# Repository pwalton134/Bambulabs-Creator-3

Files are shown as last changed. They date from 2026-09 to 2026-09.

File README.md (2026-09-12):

# Bambulabs-Creator-3
A repo containing all the mods I have made to my Flashforge Creator 3 (not pro) to bring it back to life.
THIS REPO IS AN ON-GOING WORK IN PROGRESS!
Treat it as my notepad, where I am writing what I have done to get an ageing FFC3 going again.

<h1>Alternative Slicers</h1>
Flashforge proprietary tools work well, but are dated. I wanted some of the newer more advanced slicer tools that allowed me to tinker with the settings. I found profiles for Ultimaker Cura and Orcaslicer. Neither connect directly over Ethernet, but I only use the USB drive anyway so I haven't chased this far.

<H2>Orcaslicer</H2>
This has been the most successful thus far, I found profiles that worked well from the Orcaslicer Github page, https://github.com/OrcaSlicer/OrcaSlicer/issues/9577.

<H2>Ultimaker Cura</H2>
This worked well, but I moved to Orcaslicer when that worked as I found the interface a lot better, and less buggy in Fedora. *reminder to dig out link and add here*.

<h1>Replacement Hotends</h1>
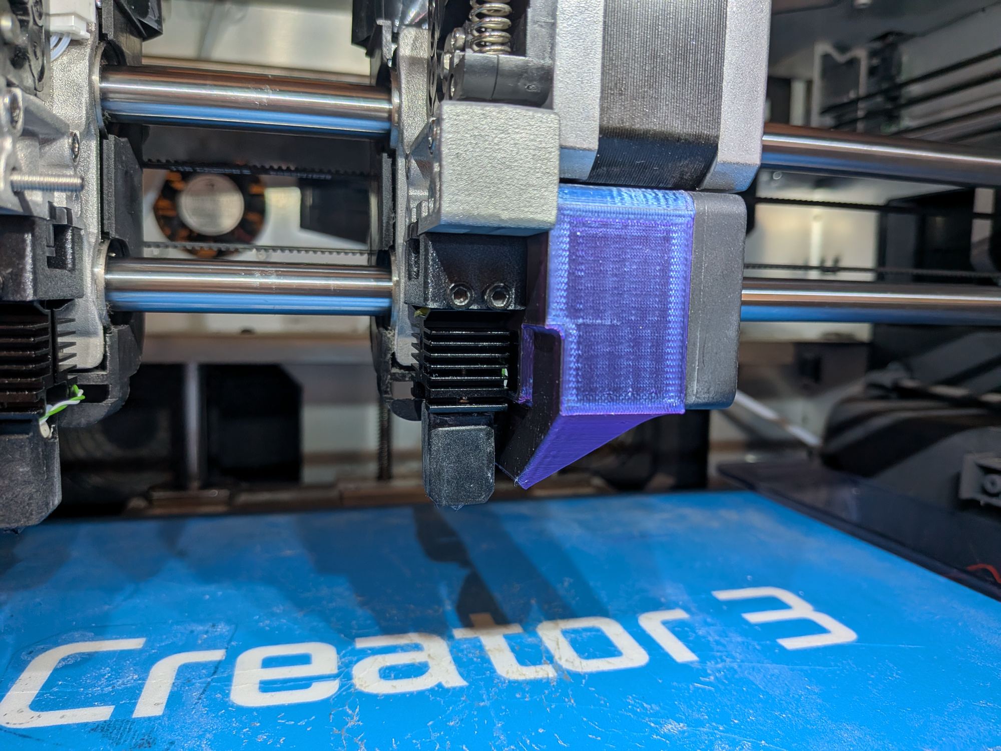
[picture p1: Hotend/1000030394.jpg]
X1C hotend installed


*These notes are being added to as I find time. I intend to add pictures and more of my learnings along the way*
My printer was a freebie from my work as they could not get replacement hotends, ultimately giving up and going to Bambu Labs printers. Obviously, getting the hotends working again was a major hurdle to overcome, as the prints were pretty awful when it did work, and the nozzles forever clogging.

To resolve this, I decided to look at what printers were out there, and what I could get on Amazon cheaply. I found the X1C hotend to be a particularly good match. It was 24V, and a similar resistance to the FFC3 hotend, and similar length. For $24 AUD I gave it a go and it was surprisingly straightforward to install. All it took was a simple 3D printed adapter, K-type thermocouple, and, using existing hardware it was surprisingly straightforward.

Things I learned along the way:
- Printer is 24V, including the hotend
- Bed homing sensor is piezo
- Temperature sensor is a K-type thermocouple
- Manual calibration of nozzle height negates the need for the homing sensor

<h2>Method:</h2>
<h3>Parts Required:</h3>

- Bambu Labs X1C 0.4mm hotend (I used this clone from Amazon https://www.amazon.com.au/LEOWAY-Upgraded-Printer-Hotend-Assembly/dp/B0GZF311Z4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)
- K-type thermocouple (bare wire worked for me)
- JST-XH 2.5mm 2P receptacle (optional, for heater wire)
- 22AWG silicone wire (optional, for heater wire)
	- Qty:2 ~90mm lengths worked well for me
- Heatshrink sized for above wire (optional, for heater wire)
- JST-XH 2.5mm 2P plug and crimps (for thermocouple, 28AWG worked for me but required folding the wire)
- 3D printed hotend adapter (ref /hotend/)
- 3D printed fan shroud (ref /hotend/)
- PTFE tube (I reused one from an old FFC3 nozzle)

<H3>Equipment Required:</H3>

 - JST-XH crimp tools
 - Soldering iron (optional, if making heater wire extenders)
 - Side-cutters
 - Hex/Allen keys

<H3>Method:</H3>
I'm writing this from memory, so please sanity check as you go.

More importantly, I am merely offering my experience on my FFC3, which has worked well for me. These are my notes. **If you choose to adapt your own machine with these notes you do so at your own risk and agree not to hold me responsible for any damage or harm that may arise. Whenever dealing with machinery, there is the possibility to damage the machine, the operator, or worse (including amputation and/or burning the place down).** This method worked on my setup, and assuming all Creator 3s are the same, may well work on another. Never leave the printer unattended during operation, especially if you have just made a change to it.

1) Print the hotend adapter.
2) Test the new X1C hotend fits into the square hole.
3) Print the fan shroud.
4) Unload the filament.
5) Turn off the printer!
6) Disassemble the extruder head, and retain all fasteners:  
	- Unplug the servo, heater, thermocouple, bed sensor, and fan;
	- Disassemble the carriage, removing the servo, fan, fan shroud, hotend, and bed sensor;
	- Disassemble the fan shroud. Remove all 4 screws.  
7) Install the 3D printed hotend adapter:
	- Place the bed sensor into the normal position;
	- Offer up the 3D printer hotend adapter, and make sure the bed sensor isn't obstructed;
	- Using the same screws from the FFC3 hotend, screw the adapter to the carriage arm.
8) Prepare the X1C hotend:
	- Extend the wires, or fabricate an extender using the silicone wire, heatshrink, and JST-XH receptacle. I made an extender, so hotend replacement was simplified in future.
 	- Trim the K-type thermocouple wire to match the length of the heater, + adapter/extension.
	- Install the ceramic heater and thermocouple onto the hotend using the supplied clip. Don't forget to add the thermal paste! One of my hotends came preassembled, so I had to disassemble it first.
	- Install the silicone boot.
9) Install the X1C hotend: 
	- Bend the top heatsink fins upwards. This serves to stabilise the hotend, kind of like a spring. I used a flathead screwdriver, pushed to the base to encourage a bend. Be very careful not to snap the fins off!
	- Place the PTFE tube into the bed sensor, and trim just shy of the base of the sensor. This took some guesswork, too short and the filament can snag when fed in, too long and the bed sensor doesn't register and the hotend may not fit.
	- With the PTFE tube in place, install the X1C hotend. Use the qty:2 lower screws from the fan shroud we disassembled earlier and push the into the hotend adapter, and through the two hotend mount holes, until the screw heads are flush. My print of the adapter meant I had some thread bite and they stuck in well. You may have to push the hotend up a little depending how far the fins were bent.
	- Connect the heater and thermocouple wires to the carriage PCB.
10) Install the fan and shroud, using the remaining qty:2 screws removed from the fan shroud earlier.
11) Connect the fan to the carriage PCB.
12) Reinstall the servo and direct drive mechanism.
13) Tidy-up!

**!!!BEFORE YOUR FIRST PRINT, SANITY CHECK THE TEMPERATURE SENSOR AND MAKE SURE IT'S READING CORRECTLY!!!**

It is easy to wire the thermocouple backwards. I initially powered up the machine and measured the temperature on the status window, both by holding onto the thermocouple and releasing it and placing it against the other intact hotend whilst it was hot and comparing the readings. I cannot stress how important it is to make sure this is reading correctly and that you must check this before heating up the new hotend.

Once installed, I ran a manual calibration of the Z-axis. Manual calibration is an option lower in the FFC3 settings page, and once enabled you run calibration as per normal, but manually setting the nozzle height using an A4 piece of paper.
So far, this has worked well and I went on to swap the second hotend, and ran a full calibration and bed level (manual in Z).
Print away!

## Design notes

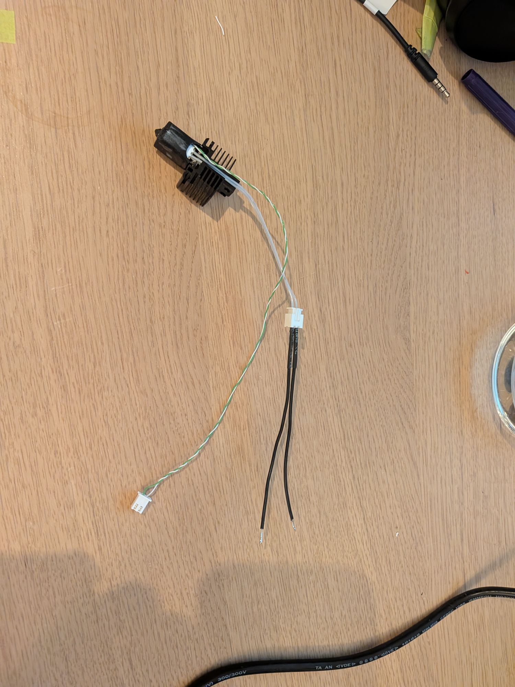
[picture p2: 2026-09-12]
Hotend/ModifiedHotend_wK-type.jpg

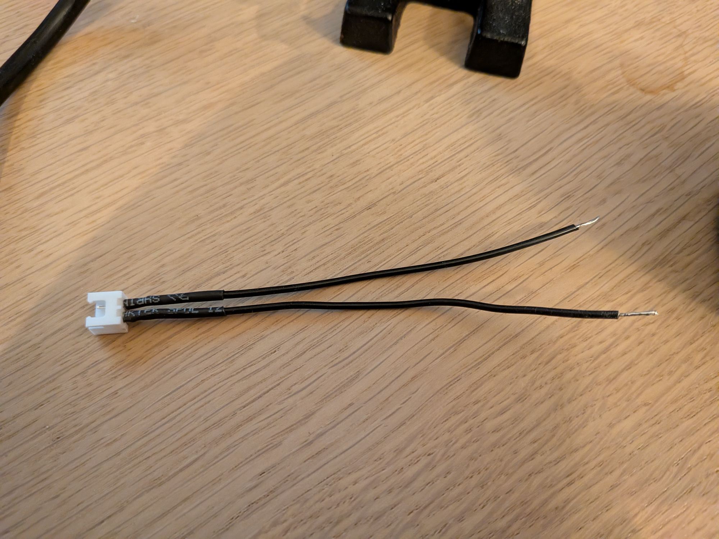
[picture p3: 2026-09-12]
Hotend/HotendHeater-Extender.jpg

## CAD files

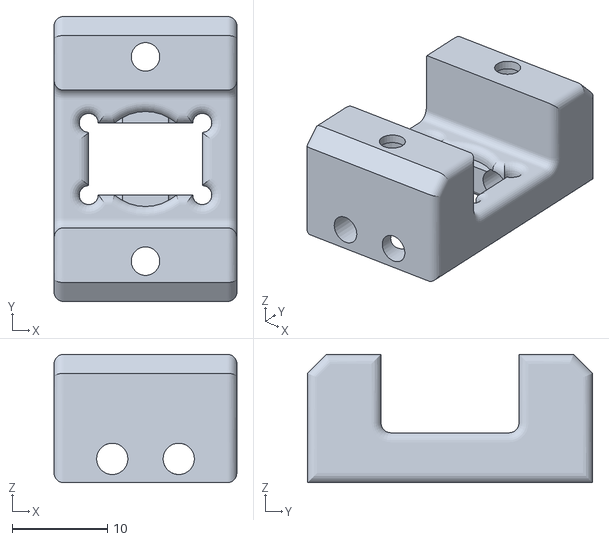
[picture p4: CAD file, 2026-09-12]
Hotend/HotendAdapter_rE.stl
19.2 x 30.0 x 13.5

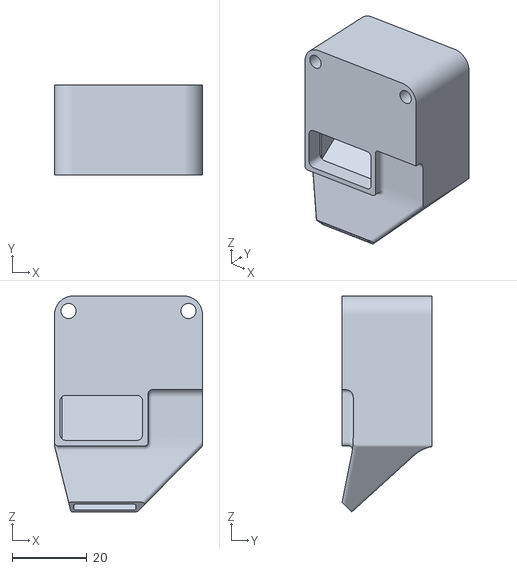
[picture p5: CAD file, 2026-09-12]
Hotend/FanShroud_rB.stl
39.5 x 24.0 x 57.6
